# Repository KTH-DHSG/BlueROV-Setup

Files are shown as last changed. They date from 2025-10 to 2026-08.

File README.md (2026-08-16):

# BlueROV-Setup

- [Using the BlueROV](setup_instructions/Usage.md): How to get started on a readily-prepared system
- [PX4 setup](setup_instructions/PX4_setup.md): How to set up software and communications
- [Jetson OS and CUDA setup](setup_instructions/Jetson_setup.md): Flashing Linux with support packages, installing CUDA, and remote desktop
- [Jetson software setup](setup_instructions/scripts/BlueROV_Jetson_setup.sh): Install script for a newly flashed Jetson
- [Internet on Jetson](setup_instructions/Jetson_internet.md): Getting internet access to Jetson via tether
- [Hardware setup](setup_instructions/hardware_setup.md): Internal hardware setup
- [Docking station setup](setup_instructions/docking_station.md): Setting up, modifying and using the docking station
- [SITL Simulation setup](setup_instructions/sim_setup.md): PX4 gz STIL simulation setup
- [Wiring diagram](setup_instructions/brov-wiring-diagram-inkscape.svg): for more details on our specific hardware adaptations

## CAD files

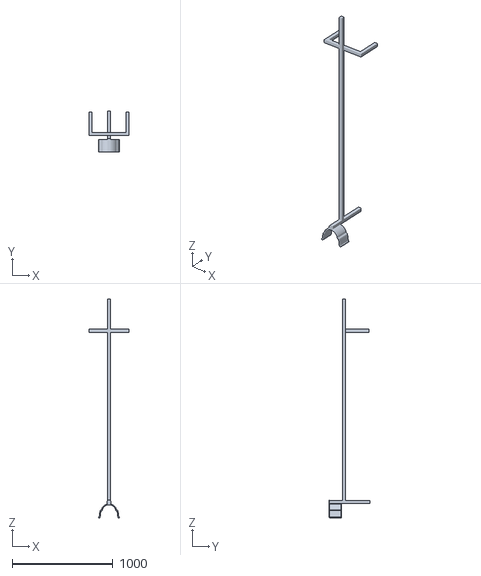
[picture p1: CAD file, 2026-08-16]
STLs/docking_station/docking station simplified.obj
400.0 x 402.0 x 2172.2

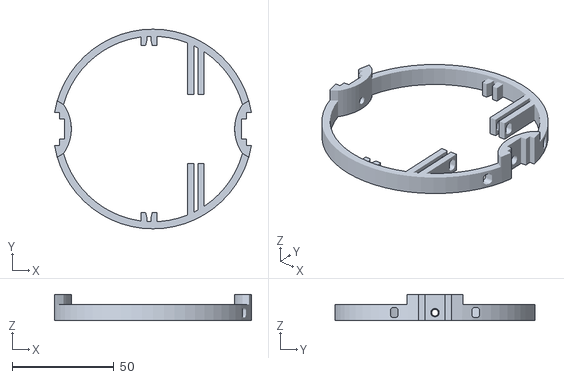
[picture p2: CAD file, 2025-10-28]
STLs/JetsonHold_ToUseAtFrontside.stl
96.7 x 98.0 x 13.0

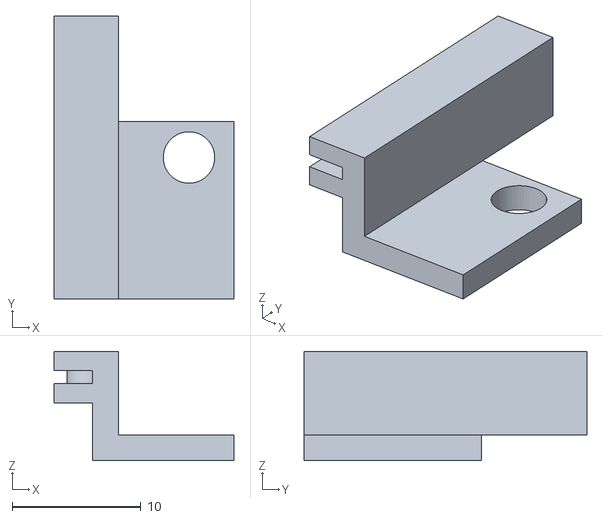
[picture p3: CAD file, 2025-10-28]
STLs/NvmeAdapter.stl
14.0 x 22.0 x 8.50

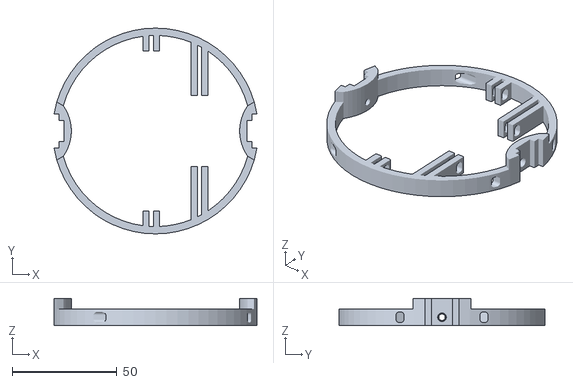
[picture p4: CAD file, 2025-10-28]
STLs/JetsonHold_ToUseAtBackside.stl
96.7 x 98.0 x 13.0

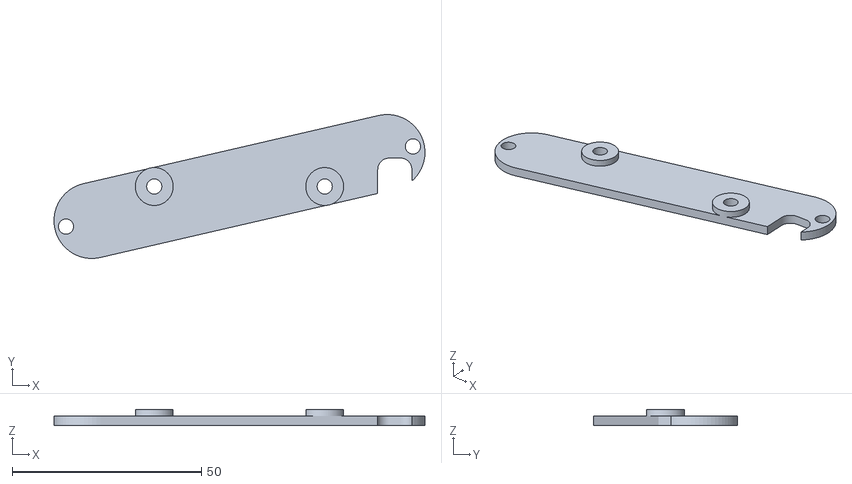
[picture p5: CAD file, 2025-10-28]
STLs/CameraHold.stl
97.9 x 38.0 x 4.30

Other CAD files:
STLs/docking_station/DockingStationv2.step
STLs/docking_station/DockingStationv2.FCStd
STLs/docking_station/DockingStationv2.stl

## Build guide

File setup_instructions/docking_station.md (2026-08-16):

# Docking station

## Introduction

The docking station was made to allow for "parking" the BlueROVs (BROV) in the water tank. The assumption is that the robot is slightly bouyant as this way it will flow up and press against the docking shell making it locked in space. The docking shell was made in such a way to allow both the BROV with the extra tube on top as well as the one without the extra tube to be able to dock in it. Admittedly, it is better for docking the BROVs with extra tube on top as it is fits better into the shell.

<p align="center">
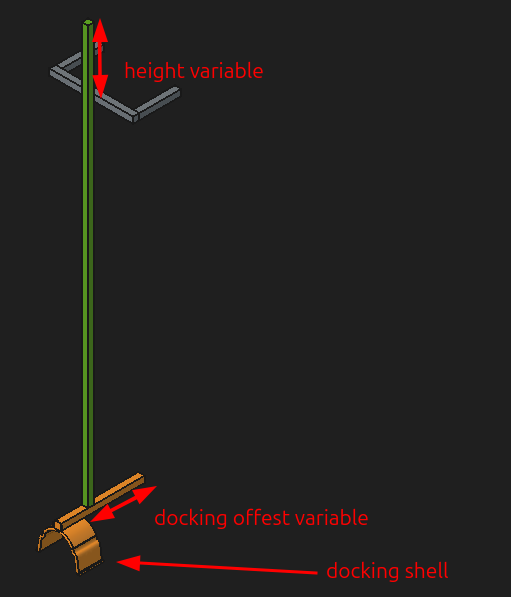
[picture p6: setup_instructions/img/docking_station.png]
  
</p>

## Files

There are four different CAD files in different formats that can be used for your project [`.obj`](../STLs/docking_station/DockingStationv2.obj), [`.step`](../STLs/docking_station/DockingStationv2.step), [`.stl`](../STLs/docking_station/DockingStationv2.stl) and [`.FCStd`](../STLs/docking_station/DockingStationv2.FCStd).

## Customization

If you need to make any changes to this setup feel free to do so. The docking station was made in [FreeCAD](https://www.freecad.org/downloads.php). It's free, open source and supported on Windows, Mac and Linux. [`.FCStd`](STLs/docking station/DockingStationv2.FCStd) is its native file format and allows for the greatest freedom in customization as well as [exporting into various other file formats](https://www.xsim.info/articles/FreeCAD/en-US/HowTo/Supported-file-formats.html). Within that file you can also export and customize the inidvidual components of the docking station.

If you simply need to change the height and docking offest values you can do so by changing the VarSet values of the name `docking station params`.

<p align="center">
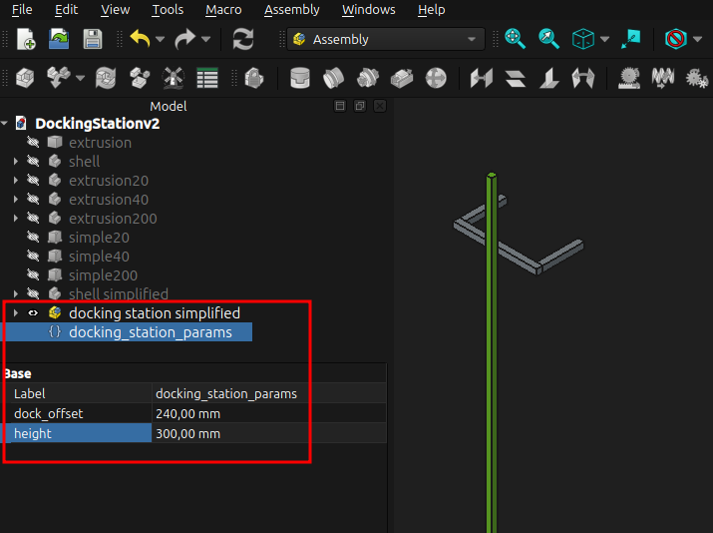
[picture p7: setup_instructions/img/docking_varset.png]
  
</p>

Feel free to explore the CAD file. There are more variables for detailed adjustments of the docking shell, its dimensions as well as the aluminum extrusion arrangement.

## Debugging

- There is an issue with exporting `.obj` files in FreeCAD 1.1.0. Exporting the part into an STL file and then opening that file and exproting it into OBJ file does the trick though.

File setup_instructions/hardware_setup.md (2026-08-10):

# Hardware Setup

This article is concerned with the internal setup of the robots. It is directed at everyone who wants to do own modifications on the hardware. For usage instructions, see [here](Usage.md).

The basic hardware setup follows the instructions by [Blue Robotics](https://bluerobotics.com/learn/bluerov2-assembly) (**Note:** Make sure to select the "Heavy configuration" when looking at the instructions.). In addition, some modifications have been made:

- Replaced flight controller from BlueRobotics/Raspberry Pi-based with PX4 Autopilot (Holybro PX6X)
- Added top tube
- Added Jetson Orin NX
- Added Intel Realsense
- Added network switch
- Software setup, not the scope of this page

The hardware instructions can still be useful for (e.g.)

- assembly of the battery tub and central tube
- how to make the robot waterproof (and test that it actually is)
- ESC setup
- how individual parts s.a. Fathom-X tether work
- ...

It is recommended to take a look at them!

## Overview

The BlueROV has three tubes:
1. Lowest:
	- Standard kit, unchanged
	- Contains battery
2. Mid:
	- Standard kit
	- Main "brain" of the robot: Contains all essential parts such as
		- Flight controller (PX6X)
		- ESCs
		- Tether interface
		- barometer, gyroscope (latter one built into PX6X)
		- ...
	- Tubes 1 and 2 are essential to control the robot in any way, even manual
	- Modification:
		- Added ethernet switch
		- Added a combined power/ethernet connection to the top tube
3. Upper:
	- Our own mod
	- Adding more autonomous capabilities through adding
		- Jetson Orin NX 16GB with [carrier board](https://connecttech.com/product/boson-for-framos-carrier-board-for-nvidia-jetson-orin-nx/)
		- Intel RealSense D435i

For a more detailed view, take a look at the wiring diagram.

## Motor setup

The motor assignments in PX4 follow the numbering of BlueRobotics:

<p align="center">
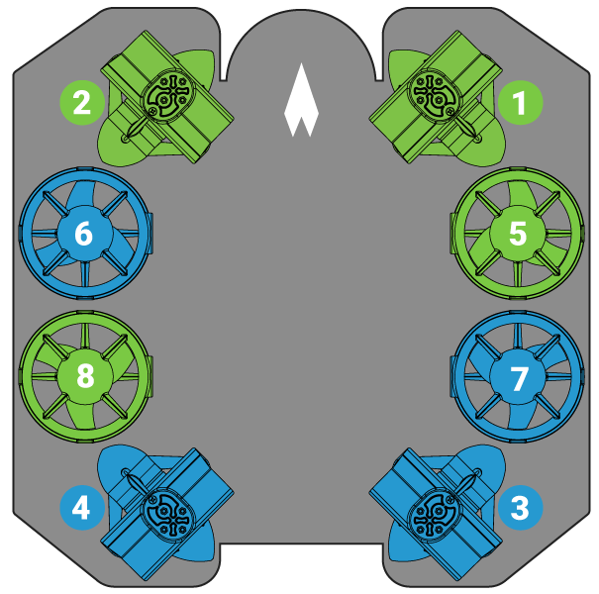
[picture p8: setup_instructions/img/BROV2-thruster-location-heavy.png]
  
</p>

<details>

<summary>💡 Help! I send the correct signal, but the wrong motors turn!</summary>

Let's say you want motor 1 and 2 to move and send an appropriate signal. Instead, motor 5 and 6 move.

In less evolved systems, you would need to make sure that the correct PWM output is connected to the correct motor. PX4, however, gives an easy way around this common problem:

Under `Q > Vehicle Setup > Actuators`, you can got to the 'PWN MAIN'/'PWM AUX' tab. For each PWM output, you can select a routing of the output in the dropdown, i.e. that 'MAIN 1:' is 'diabled', acts as 'Motor 1', ...

You can try out the current routing in the 'Actuator Testing' tab and move each motor individually. (Take care of your fingers and other vulnerable things. Also don't run the motors for too long, they are designed to operate in water and will overheat outside.)

<p align="center">
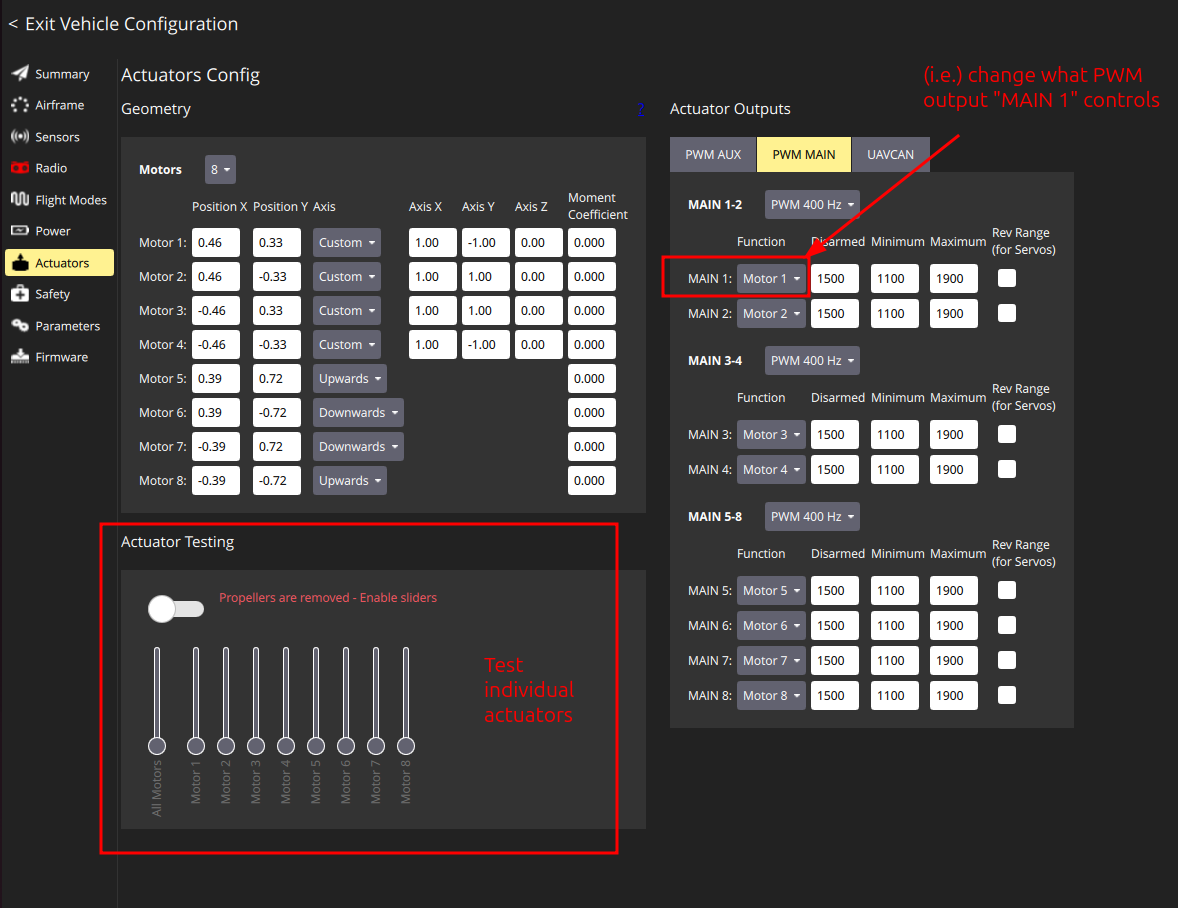
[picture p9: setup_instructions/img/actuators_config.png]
  
</p>

</details>

## Vacuum testing

If new tubes / cables between tubes / ... are installed, a prelimiary vaccum test should be preformed. In general, the instructions from BlueRobotics [here](https://bluerobotics.com/learn/bluerov2-assembly/#preliminary-vacuum-test) can be followed. Make sure to

- Start with the equipment test. If the vacuum pump + connections themselves are not tight, try with zip ties.
- Test all tubes at the same time, otherwise it will not work. Combine as many T-formed hose connectors as you need to connect to all tubes.
- Disassemble the equipment after use: Over time, the hoses will otherwise take the shape of the connectors, so the pressure at the connection pieces decreases and they will start to leak air.

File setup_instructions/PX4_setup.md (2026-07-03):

# PX4 Setup

---

## Table of Contents

- [What's PX4?](<PX4_setup#What's PX4?>)
- [Interfaces](PX4_setup#Interfaces:)
- [Flashing and Setting up PX4](<PX4_setup#Flashing and Setting up PX4>)
- [Communication Setup](<PX4_setup#Communication Setup>)
  - [User-side setup](<PX4_setup#User-side setup>)
  - [BlueROV-side setup](<PX4_setup#BlueROV-side setup>)
    - [Jetson](PX4_setup#Jetson)
    - [PX4](PX4_setup#PX4)
    - [PX4 Setup](<PX4_setup#PX4 Setup>)
- [Common Issues](<PX4_setup#Common Issues>)

---

## What's PX4?

- open software/hardware project serving as "brain" for all sorts of drones
- Advantages:
  - Good software intergration: Easy integration of sensors etc., safety features, controller integration, ...
  - Open Source: Multiple manufacturers produce for PX4, if one product is discontinued, there is a plug-and-play replacement from another manufacturer.
  - Good software integration with e.g. QGroundControl
- Do not confuse:
  - PX4 Autopilot: The open-source system/project itself
  - PX6X: The specific hardware on which we are running PX4 Autopilot

</details>

## Interfaces:

- Physical Interfaces
  - Tether:
    - connect Fathom-X tether interface via USB to your computer
    - Establishes an ethernet connection to the whole BlueROV (i.e. the PX6X, but also e.g. the Jetson)
    - setup instructions: see below (todo: insert link)
  - USB-C:
    - connect directly from your computer to PX6X (requires removal of tube)
    - Fallback if PX6X is not available over Ethernet
    - For now needed to update the firmware of the PX6X
- Software interfaces:
  - QGroundControl
    - Allows to set most settings in an easy-to-use graphical interface
    - Console interface under "Analyze Tools > MavLink Console" for advanced use cases
  - ROS2 interface: MavLink to ROS2 bridge (todo: insert link)

---

## Flashing and Setting up PX4

Theoretically, the flashing should be easily doable through QGroundControl ([PX4 Doc > Config > Firmware](https://docs.px4.io/main/en/config/firmware.html)). For current firmware version v1.16.0 this however leads to an incomplete install (BlueROV airframe not selectable), so this procedure works instead:

Follow the [spacelab setup](https://atmos.discower.io/pages/PX4/) for the first three steps ("PX4 Autopilot" section).

The firmware installation works similar, but we choose a _different target_ and _different default namespace_:

1. Connect the Pixhawk to your computer via serial. Make sure QGroundControl is closed.
2. Navigate to the cloned PX4-Autopilot directory and ensure that the build environment is clean.

```bash
make clean
```

3. Export the name of the robot to setup the DDS.

```bash
export PX4_UXRCE_DDS_NS=<robot_name>
```

4. Upload the firmware using:

```bash
make px4_fmu-v6x_uuv upload
```

> [!Note]
> The target we use below is currently only available in the development release (v1.16.0.rc1), not in the latest stable release.

---

## Communication Setup

Communication mainly follows standard networking approaches -> Knowledge of setting up IP networks is advantageous

- Fathom-X is simply a transparent ethernet bridge (without own IP adress or so), whole network is a standard ethernet network
- PX6X needs to be configured for communication over Ethernet. General instructions are under [PX4 docs > Advanced Config > Ethernet Setup](https://docs.px4.io/main/en/advanced_config/ethernet_setup), our setup follows:

Goal: Have all three BlueROVs connected to the same computer

Current setup: Follow original setup closely

USB-Switch connecting to all Fathom-X interfaces. Each USB-cable should be detected as individual USB-ethernet interface in system network settings.

### User-side setup

Probably the easiest is to connect and set up one BlueROV at a time. Each Fathom-X Interface box (FXTI) connection gets its own network setting with own IP adress and subnet.

| BlueROV | Laptop IP | Subnet Mask (Netmask) | Gateway | Status |
| --- | --- | --- | --- | --- |
| Splash | 192.168.0.1 | 255.255.255.0 | 0.0.0.0 | Done |
| Bubble | 192.168.1.2 | 255.255.255.0 | 0.0.0.0 | Done |
| Glub | 192.168.2.3 | 255.255.255.0 | 0.0.0.0 | To be done |

1. Go to Settings > Network > Add
2. Under Identity > Name, choose
   - a profile name (we suggest the name of the BROV)

3. Under IPv4, choose
   - IPv4 Method: Manual
   - Fill the corresponding fields from the table above

4. Apply settings

> [!NOTE]  
> The first time you connect to QGC with the BlueROV2 and the Fathom, it can take a long time for the PX4 to be detected.

### BlueROV-side setup

#### PX4

The network setup on robot side can be changed through QGroundControl. The current configuration is

| BlueROV | UXRCE_DDS_KEY | Fathom (Laptop) IP | PX4 IP | Subnet Mask | Status |
|---|---|---|---|---|---|
| Splash | 1 | 192.168.0.1 | 192.168.0.10 | 255.255.255.0 | Done |
| Bubble | 2 | 192.168.1.2 | 192.168.1.11 | 255.255.255.0 | Done |
| Glub | 3 | 192.168.2.3 | 192.168.2.12 | 255.255.255.0 | To be done |

>[!Important]
> Each BROV should have a different UXRCE_DDS_KEY. This can be changed in the parameters tab in QGroundControl.

To ensure that we can run multiple BROVs at the same time, we must ensure that they run on separate subnets. They should already be set correctly and **we recommend to not touch this**, but in case you need to you can change them by doing the following: go to "Analyze Tools > MavLink Console". Then type params (or any other keyword) so that you can see the console shows "nsh>" instead of just ">". Then input:

```
# Splash
echo DEVICE=eth0 > /fs/microsd/net.cfg
echo BOOTPROTO=fallback >> /fs/microsd/net.cfg
echo IPADDR=192.168.0.10 >> /fs/microsd/net.cfg
echo NETMASK=255.255.255.0 >> /fs/microsd/net.cfg
echo ROUTER=192.168.0.1 >> /fs/microsd/net.cfg
echo DNS=192.168.0.1 >> /fs/microsd/net.cfg
reboot
```

```
# Bubble
echo DEVICE=eth0 > /fs/microsd/net.cfg
echo BOOTPROTO=fallback >> /fs/microsd/net.cfg
echo IPADDR=192.168.1.11 >> /fs/microsd/net.cfg
echo NETMASK=255.255.255.0 >> /fs/microsd/net.cfg
echo ROUTER=192.168.1.2 >> /fs/microsd/net.cfg
echo DNS=192.168.1.2 >> /fs/microsd/net.cfg
reboot
```

```
# Glub
echo DEVICE=eth0 > /fs/microsd/net.cfg
echo BOOTPROTO=fallback >> /fs/microsd/net.cfg
echo IPADDR=192.168.2.12 >> /fs/microsd/net.cfg
echo NETMASK=255.255.255.0 >> /fs/microsd/net.cfg
echo ROUTER=192.168.2.3 >> /fs/microsd/net.cfg
echo DNS=192.168.2.3 >> /fs/microsd/net.cfg
reboot
```

Rebooting through the MavLink Console sometimes does not work. You can also go to Vehicle Configuration > Parameters tab and then click Tools > Reboot Vehicle.

Now you should be able to run the Micro-XRCE-DDS-Agent and use ROS2 topics as described in the simulator section: [sim_setup.md](sim_setup.md). 

>[!Note] Note that if you have changed the Fathom (laptop) address you need to change the UXRCE_DDS_AG_IP parameter in the Parameters tab of QGC to the signed int32 equivalent of your Fathom IP address.

#### Jetson

Under Settings > Network > Realtek Ethernet set a static IP with the addresses stated above. The process is the same one as the user-side setup without the extra steps.

> [!IMPORTANT]
> This setup does _not_ allow the Jetson to access the internet. To achieve this, two methods are possible (plus the alternative setup described below).
>
> 1. Enable IP forwarding and set up NAT (Network Address Translation) on your desktop computer
> 2. Take of the shell on the front (camera side), connect an ethernet cable to the second ethernet port of the Jetson
>    Personally, I think that the alternative setup has a lot of advantages and simplifies working with the robots a lot.
---

## Common Issues
PX4 Issues:

1. Micro XRCE DDS doesn't connect to the companion laptop.
   When the Micro XRCE DDS agent doesn't detect the DDS client running on PX4, it most likely means that the IP set for the companion laptop is not the same set in the DDS config. To check the IP targeted by the client on PX4, do the following: Open **QGround**/**Analyze Tools**/**MAVlink Console** and type in the terminal

   ```bash
    xrce_dds_client status
   ```

   This should output the current targeted IP of the DDS client running on PX4. Make sure the companion computer that is supposed to receive the ROS2 messages has the same IP configured in the network settings.

   The IP used by the DDS client on PX4 can be changed if need be. To do so go into **QGround**/**Parameters** and search for **XRCE_DDS_IP_AG** and change that parameter to the IP you want the client to target.

   > [!Caution]
   > The parameter used in QGround is in `int32` format so the IP has to be converted to a binary representation first and then saved in `int32`. This can be done using C/C++ type `int32_t`.

2. Gazebo simulation doesn't have the BROV2 models.
   The PX4 repository used for the PX4 flashing is the official one, hence it doesn't have the required files for Gazebo simulation. To get the PX4 fork that has the Gazebo files, follow the simulation instructions here [https://github.com/KTH-DHSG/BlueROV-Setup/blob/main/setup_instructions/sim_setup.md](https://github.com/KTH-DHSG/BlueROV-Setup/blob/main/setup_instructions/sim_setup.md)

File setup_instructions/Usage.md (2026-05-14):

# Quick tutorial

This is a short tutorial on how to use the BlueROVs. We recommend first doing the SITL gz simulator setup in [SITL Simulation setup](sim_setup.md).

## Table of Contents
- [Open and close the tubes](#open-and-close-the-tubes): Open and close the BlueROV, e.g. for loading batteries
- [Operate in manual mode](#operate-in-manual-mode): Establish connection to robot, arm the robot, manual steering
- [Connect to Jetson](#connect-to-jetson): Connect your PC/laptop to the Jetson
- [Start PX4/ROS communication](#start-px4ros-communication): Establish the bridge between PX4 messages and ROS messages. Allows to record data/control over ROS/...
- [Setup lights switch](#lights-switch): how to setup the lights to a Joystick switch.

## Operate in manual mode

1. Setup: If not already happened, 
- Install QGroundControl from the official resources
- Make sure to follow the user-side setup in [PX4_setup.md](PX4_setup.md).

> [!NOTE]
> If you are operating **Bubble** (the BlueROV2 without the extra tube with the stereo d435i cam and the Jetson) ignore all the instructions from the [Connect to Jetson](#connect-to-Jetson) all the way to the end. 

2. Connect the battery to the XT90 connector (check the [Open and close the tubes](#open-and-close-the-tubes) section to know how open the tube where it resides). Make sure to hear the two difference notes with a space of about 3s of silence in between, if you only hear a continuous song the BlueROV2 has not started the ESCs correctly and you need to unplug and plug the battery again. Another way to see if it has started correctly is that the PX4 should have two continuous lights, a green and an orange one.
<p align="center">
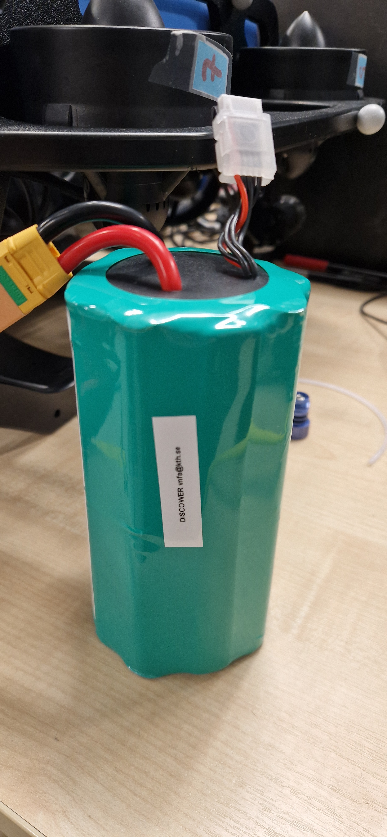
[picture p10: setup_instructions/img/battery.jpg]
  
</p>

3. Connect the Fathom-X Interface with a USB port on your computer on the one side and with the BlueROV tether on the other.

<p align="center">
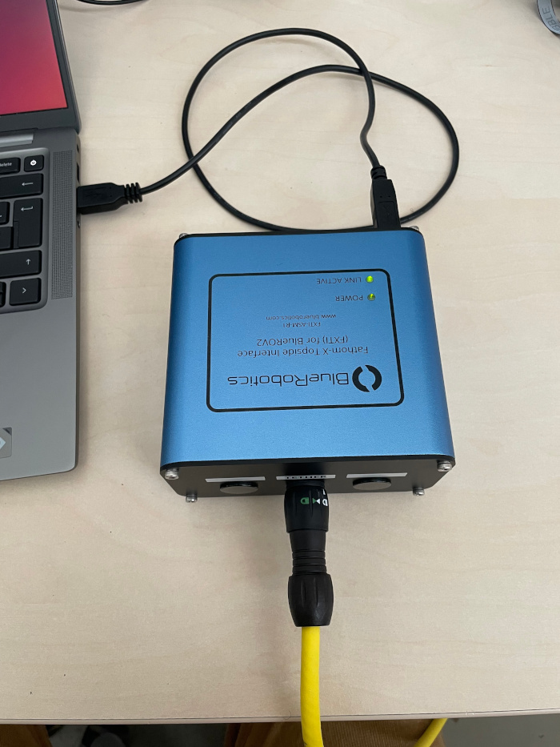
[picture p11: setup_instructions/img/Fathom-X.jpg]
  
</p>

4. Open QGroundControl. After a short while, the robot should be connected and it should look like this:

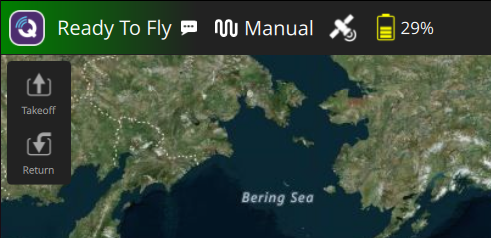
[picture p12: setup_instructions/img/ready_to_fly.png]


> [!NOTE]
> It might also look like this:
>
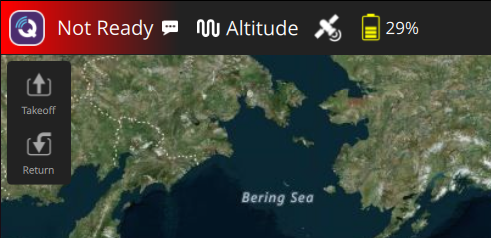
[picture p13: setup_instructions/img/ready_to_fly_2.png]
> 
> 
> You can most probably ignore this warning. If not, QGroundControl will give you a helpful error during arming.
> 
> <details> <summary>Reason for warning:</summary> This can happen as no "classical" radio remote control is configured - we use the BlueROV only via QGroundControl and Joystick. You can ignore the red "Not Ready" therefore, the vehicle is connected anyways. To verify that this is the reason for the warning, go to "Q">"Vehicle Configuration". Everything should be green besides of "Radio". </details>

If the robot is not connected after some time, remove and re-plug the USB connection. If the issue persists, check your network setup.

5. Plug in the joystick, arm the vehicle and have fun! If you are connected, but something is not working, go to "Q">"Vehicle Configuration" and resolve the issues (most likely you need to tick the Enable joystick box in the Joystick tab).

To arm the vehicle, make sure that "Manual" mode is selected from the dropdown in the top bar. Then, click the following:

<p align="center">
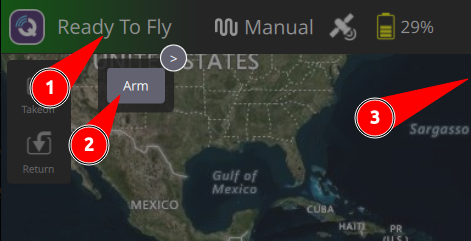
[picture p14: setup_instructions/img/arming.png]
   
</p>

We also strongly recommend to setup an arm (button 6 in xbox) and a disarm (button 4 in xbox) button before any operations so you can safely and quickly disarm it if needed. This can be setup in Vehicle Configuration > Joystick > Button Assignment.

Connecting the Xbox controller through Bluetooth is also always recommended to reduce the number of cables in the tank. To do so you need to first turn the controller (maintain press on the Xbox symbol - turning it off is done by a longer maintain press) and put it in binding mode (press the smaller button on the top of the controller). You should then be able to see and pair it using common Ubuntu Bluetooth window. If you are experiencing issues we recommend installing the [xpad-neo](https://github.com/atar-axis/xpadneo) driver and updating the firmware in the controller (through the Windows Xbox app). To test it works you can use the [gamepad testet](https://hardwaretester.com/gamepad).

> [!NOTE]
> Other people might bind your controller while you are away and you will need to re-pair it again afterwards, if you are seeing your controlling connecting and disconnecting from Bluetooth really fast, you need to re-pair.

<p align="center">
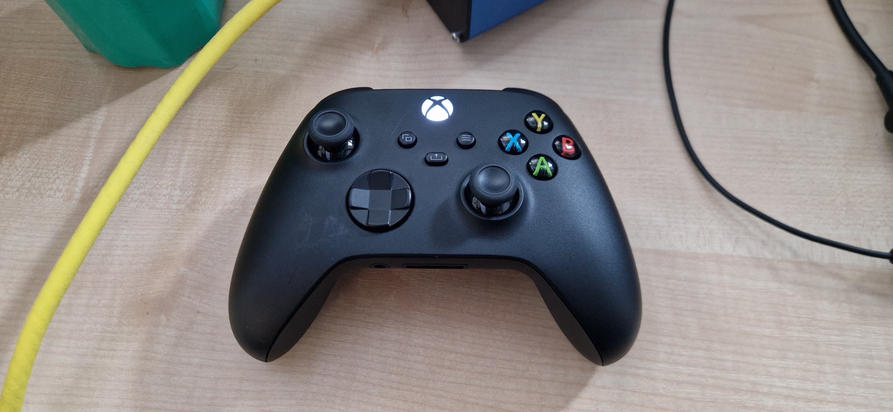
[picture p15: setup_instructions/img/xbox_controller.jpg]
   
</p>

For control over ROS, you need to [start ROS communication](#start-px4ros-communication) and change the mode to "offboard". **NOTE that for Bubble we use a different connection setup, described in the BlueROV-side setup section in [PX4_setup.md](PX4_setup.md).**

## Connect to Jetson

1. See steps 1 and 2 above. 

2. Verify that you have a connection to the robot by opening QGroundControl or 
```
ping 192.168.0.<your robots IP>
```

3. Connect to the Jetson over SSH via
```
ssh discower@<jetson_IP>
```
for user and PW 'discower'. If it does not work, change the username from discower to glub or splash (depending on which robot you use).

4. Optional: Start all ROS services, e.g. start the Intel RealSense node.
```
ros2 run realsense2_camera realsense2_camera_node
```

> [!NOTE]
> The Jetson has by default no access to the internet. Refer to [PX4_setup.md](PX4_setup.md) for more information regarding package installation etc.

## Start PX4/ROS communication

PX4 and ROS2 can communicate using the [MicroXRCE-DDS client](https://docs.px4.io/main/en/ros2/user_guide#installation-setup). The client should already be installed on the Jetson. Once it is started, you can see all PX4 topics in ROS and command the robot from ROS. Start the connection like this:

1. SSH to the Jetson and call
```
MicroXRCEAgent udp4 -p 8888
```
2. In QGroundControl, go to "Q">"Analyze Tools">"MAVLink Console" and call
```
uxrce_dds_client start -t udp -p 8888 -h <JETSON_IP>
```

You can test your connection using `ros2 topic list`.

## Open and close the tubes

**Opening the tubes**

1. Remove the locking chord

<p align="center">
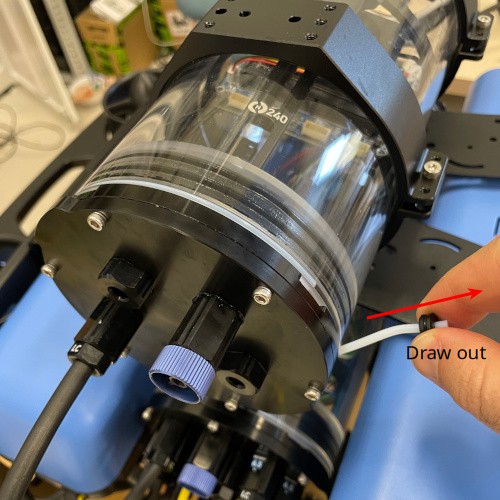
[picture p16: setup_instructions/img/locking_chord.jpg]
  
</p>

2. Remove the pressure relief valve

<p align="center">
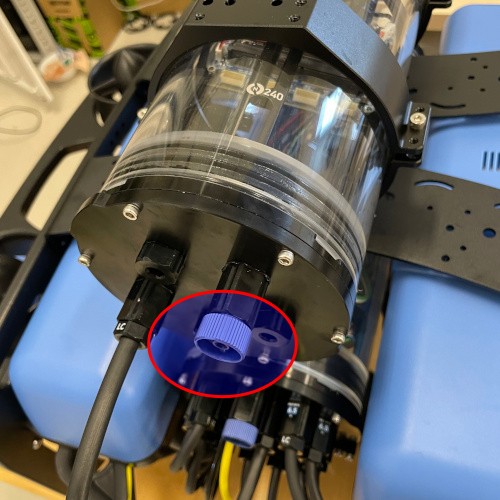
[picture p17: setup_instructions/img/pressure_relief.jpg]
  
</p>

3. Detach the end cap with the black enclosure prying tool

<p align="center">
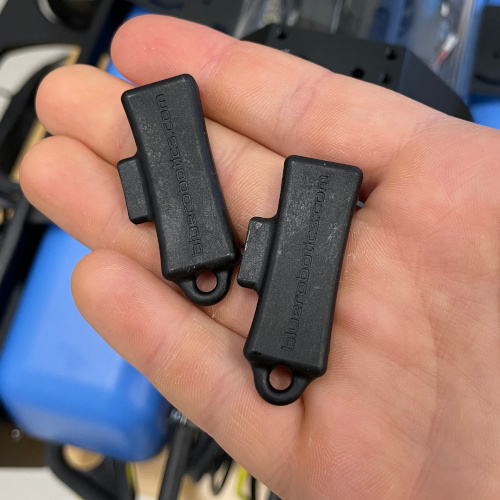
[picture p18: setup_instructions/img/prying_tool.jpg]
  
</p>

<p align="center">
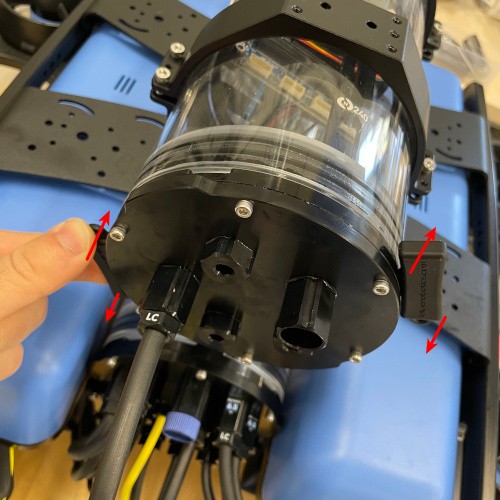
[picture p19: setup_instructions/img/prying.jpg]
  
</p>

**Closing the tubes**

Basically everything in reverse:

1. Make sure the pressure relief valve is detached
2. Press in the end cap. Make sure that no cable is damaged
3. Attach the pressure relief valve
4. Attach the locking chord. They come in different lengths depending on tube size.

## Lights switch
1. To setup the light switch you first need to modify your QGC. Go to Documents/QGroundControl/MavlinkActions folder and add a file called actuators.json with the following inside:
```bash
{
  "version": 1,
  "fileType": "MavlinkActions",
  "actions": [
    {
      "label": "Lights ON",
      "description": "Turn lights on",
      "mavCmd": 187,
      "param1": 1
    },
    {
      "label": "Lights OFF",
      "description": "Turn lights off",
      "mavCmd": 187,
      "param1": -1
    }
  ]
}
```

2. Next, enter QGC, go to the Application Settings > Fly View and in MavLink Actions select your actuators.json for both Fly View Actions and Joystick Actions.

3. Then, go to Vehicle Configuration settings > Actuators, and in the PWM AUX tab on the right select the first AUX 1 to be Peripheral via Actuator Set 1.

4. Lastly, go to Joystick > Button assignment and setup one button to be Lights ON and one to be Lights OFF. Now you can arm the vehicle and test the lights!

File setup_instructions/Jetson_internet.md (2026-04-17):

# BROV Jetson Internet Connection Setup

## Description

The goal of this tutorial is to allow the Jetson computer access the internet via the BROVs ethernet thether connection.

## Prerequisites

You need to first setup the ethernet connection between BROV and your laptop. If you are able to ssh to Jetson then you're good in that regard.

## Procedure

### Laptop-side setup:
First, we need to find the network devices that interface the Internet \<Internet-facing\> and the BROV2 \<LAN-facing\>.

To find \<Internet-facing\> we run:
```bash
ip route | grep default
```
Which can produce ouput similar to this:
```bash
default via 10.0.0.1 dev enxc0470e89b222 proto dhcp metric 103 
default via 10.0.0.1 dev wlp113s0f0 proto dhcp metric 600 
```
The \<Internet-facing\> can be then either <code>enxc0470e89b222</code> which is the ethernet adapter connected to the lab, and <code>wlp113s0f0</code> which is the WiFi adapter.

To find \<LAN-facing\> we run (in a similar fashion):
```bash
ip route | grep 192.168
```
Which can produce the output:
```bash
192.168.0.0/24 dev enx00e03336699a proto kernel scope link src 192.168.0.3 metric 102
```
Now, the last IP address in the line above is the IP we assigned to the laptop using the GUI when first setting up the network over the tether.

```bash
# configure the iptables
sudo iptables -t nat -A POSTROUTING -o <Internet-facing>  -j MASQUERADE
sudo iptables -A FORWARD -i <Internet-facing> -o <LAN-facing> -m state --state RELATED,ESTABLISHED -j ACCEPT
sudo iptables -A FORWARD -i <LAN-facing> -o <Internet-facing>  -j ACCEPT
```
Then save the config to make it pesistent:
```bash
# donwload persistent iptables and save the current settings
sudo apt install iptables-persistent
sudo netfilter-persistent save

# make the forwarding permament
echo "net.ipv4.ip_forward=1" | sudo tee -a /etc/sysctl.conf
sudo sysctl -p
```

### Jetson-side setup:
All of the required changes to the settings should have been already installed automatically by this stage of the setup process.

**Check**:
```bash
sudo cat /etc/netplan/01-netcfg.yaml
```
If nothing is displayed, it means that the automatic setup was unsuccessful and the following needs to be done on the Jetson.

**Option 1**: Use the script <code>jetson_internet_setup.sh</code> located in the <code>scripts/</code> directory.

**Option 2**: Follow the tutorial below:

Find Jetson LAN-facing device:
```bash
ip route | grep default
```
Which produces very similar output to the previous cases. Chose the device that has the LAN connection. We will call it \<Jetson-LAN-facing\>

```bash
# download netplan
sudo apt install netplan.io

# create a new netplan rule
sudo tee /etc/netplan/01-netcfg.yaml << 'EOF'
network:
  version: 2
  ethernets:
    enP8p1s0:
      dhcp4: false
      addresses:
        - 192.168.0.22/24
      routes:
        - to: default
          via: 192.168.0.3
      nameservers:
        addresses: [8.8.8.8, 8.8.4.4]
EOF

# fix the permissions and apply
sudo chmod 600 /etc/netplan/01-netcfg.yaml
sudo netplan apply
```
**IMPORTANT!** Change the Jetson's network device name from <code>enP8p1s0</code> to \<Jetson-LAN-facing\>.
This netplan setup assumes the laptop has configured its IP to be <code>192.168.0.3</code>, so adjust this line if the IP is different. Similarily, the IP <code>192.168.0.22/24</code> is the IP we want to assign to the BROV2, change this line if you want a different one.

Now check if the Jetson has access to the Internet:
```bash
# ping google to see if it resolves
ping -c 3 google.com
# ping the laptop to see if it resolves
ping -c 3 192.168.0.22

```

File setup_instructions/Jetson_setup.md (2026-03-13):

# Jetson OS and CUDA Setup

This tutorial encopases all that is needed to install Linux operating system with ConnectTech support packages.

## Table of Contents

- [Jetson OS and CUDA Setup](#jetson-os-and-cuda-setup)
  - [Table of Contents](#table-of-contents)
  - [Before Installation](#before-installation)
  - [Flashing Jetson with the Operating System](#flashing-jetson-with-the-operating-system)
  - [Configuring Internet Access](#configuring-internet-access)
  - [Installing Nvidia SDK](#installing-nvidia-sdk)
  - [Software Setup After Installation](#software-setup-after-installation)
    - [Setting up remote desktop using NoVNC](#setting-up-remote-desktop-using-novnc)
    - [Setting up Nvidia TensorRT for YOLO acceleration](#setting-up-nvidia-tensorrt-for-yolo-acceleration)
  - [Reference Links](#reference-links)

## Before Installation

Before we can begin the installation process, we need to install [Nvidia SDK Manager](https://developer.nvidia.com/sdk-manager). This step requires an active Nvidia account and unfortunately cannot be skipped.

1. Enable the recovery mode on the Jetson. To enable the recovery mode follow the steps described in the [manual](https://connecttech.com/ftp/pdf/CTIM-00095_Boson_Boson22_Manual.pdf). In short, connect the Jetson to its power supply, press and hold the recovery button (SW3) and press-release the reset button (SW2). When in the recovery mode, the radiator fan should spin at maximum speed.

2. Connect the Jetson using its USB C port to your computer.

## Flashing Jetson with the Operating System

1. Open Nvidia SDK Manager.

2. Select Jetpack 6.2 rev. 2 (it can be hidden under all versions button).
<p align="center">
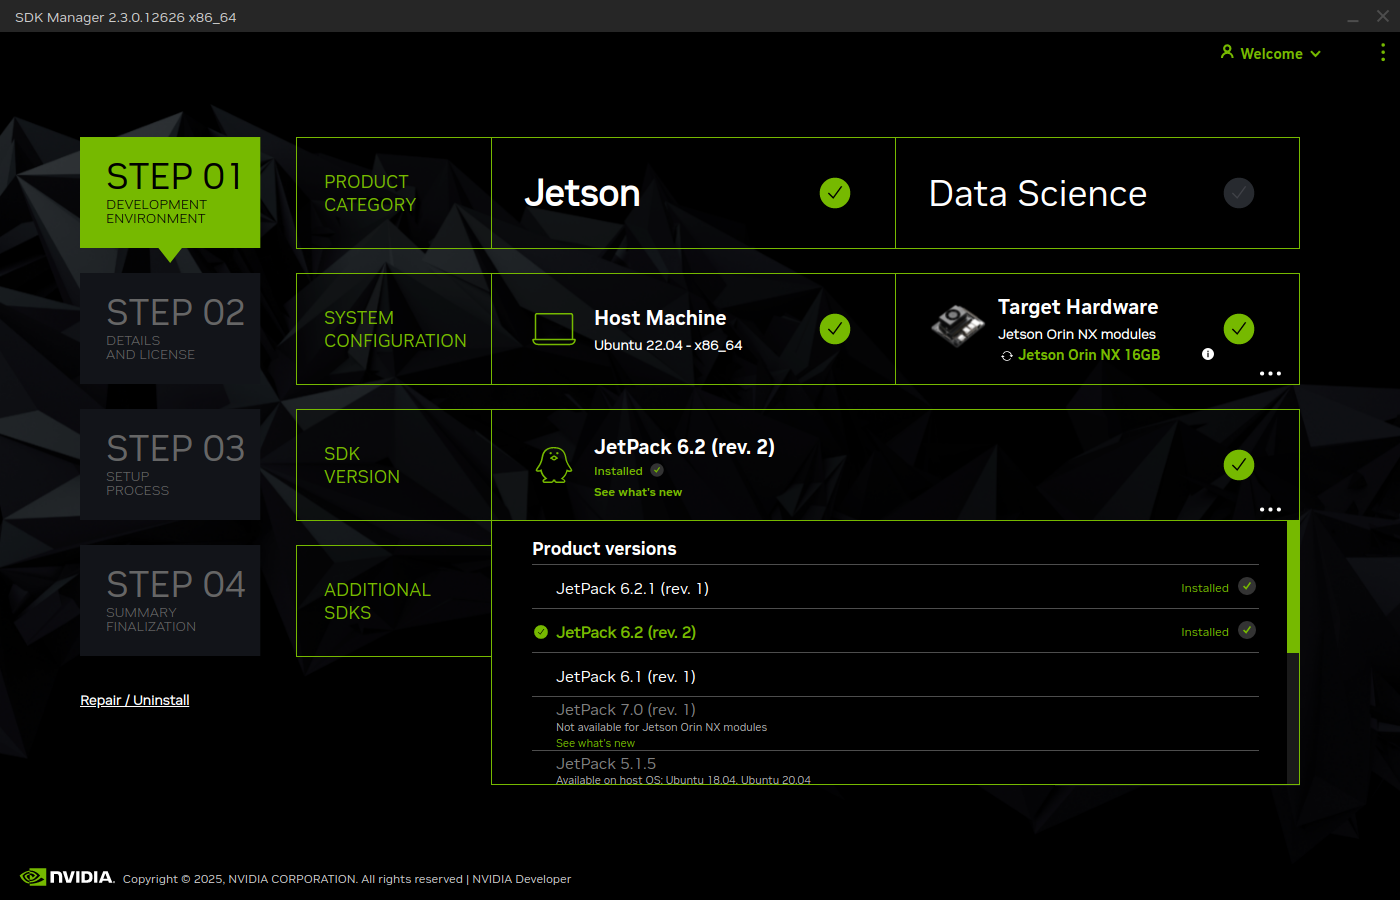
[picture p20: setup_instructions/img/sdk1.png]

</p>
3. Select the following modules to be installed:
<p align="center">
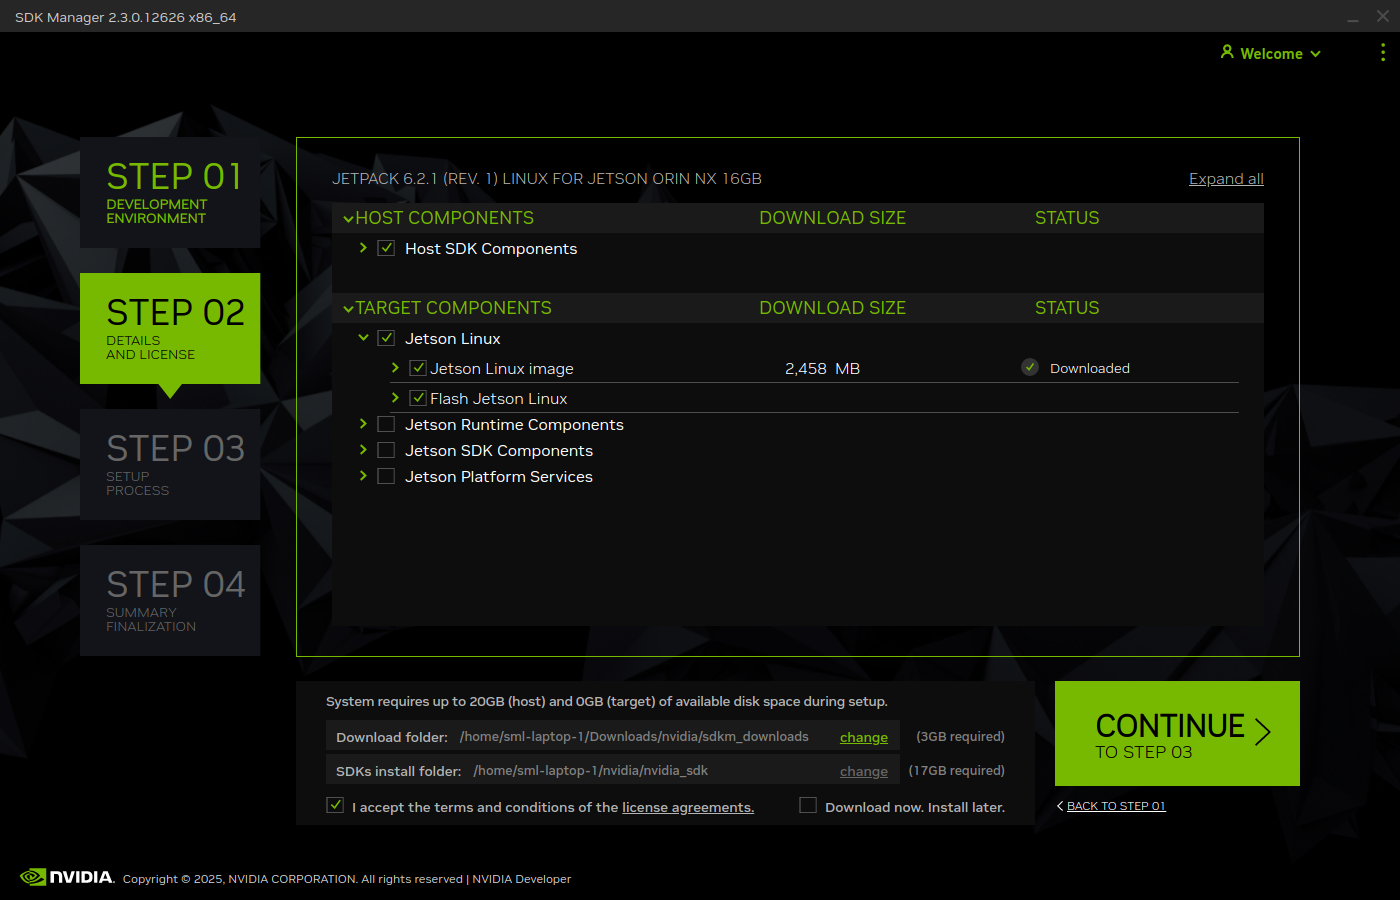
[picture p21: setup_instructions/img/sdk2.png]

</p>
4. After downloading the modules, on the prompt to flash the board, press skip.
5. Download a suitable [CTI support package for Jetpack 6.2](https://connecttech.com/resource-center/l4t-board-support-packages/) (DO NOT download RealTime OS), or use this [direct link to the package](https://connecttech.com/ftp/Drivers/CTI-L4T-ORIN-NX-NANO-36.4.3-V009.tgz). Make sure that the extracted folder containing the files is named <strong>CTI-L4T</strong>.
6. Unzip the support package archive and make sure the top-most folder is called <strong>CTI-L4T</strong> and place it here: <code>/home/$USER/nvidia/nvidia_sdk/JetPack_6.2_Linux_JETSON_ORIN_NX_TARGETS/Linux_for_Tegra</code> where <strong>$USER</strong> is your account username.

7. From terminal, go into <strong>CTI-L4T</strong> directory and execute \
   <code>sudo chmod +x install.sh</code> \
   <code>sudo ./install.sh</code> \
   <code>cd ..</code> \
   <code>sudo ./cti-flash.sh</code>
8. When prompted, select the appropriate settings for the current board (Boson for Orin, Orin NX, Base, Default).
9. <strong>TIP!</strong> After flashing is complete disconnect the USB C cable from the computer flashing the Jetson (after the flashing script exits). Sometimes it may prevent the Jetson from booting up and flashing will have to be done again.

## Configuring Internet Access

To proceed with the configuration, we have to enable Internet access. One way of doing this is to connect the Jetson with an ethernet cable to the local network and using one of the monitors in the lab to proceed with the basic Linux user setup. After that is complete, open the terminal and get the assigned IP address using the command:

<code>hostname -I</code>

For configuring the Internet access with the tether attached, see [Getting internet access to Jetson via tether](Jetson_internet.md).

## Installing Nvidia SDK

After having configured the Internet access, we can proceed with the installation of Nvidia graphics card drivers.

1. Open Nvidia SDK Manager.
2. Proceed with the same selection as in [Flashing jetson with the Operating System](#flashing-jetson-with-the-operating-system) until module selection.
3. In the module selection, select the following:
<p align="center">
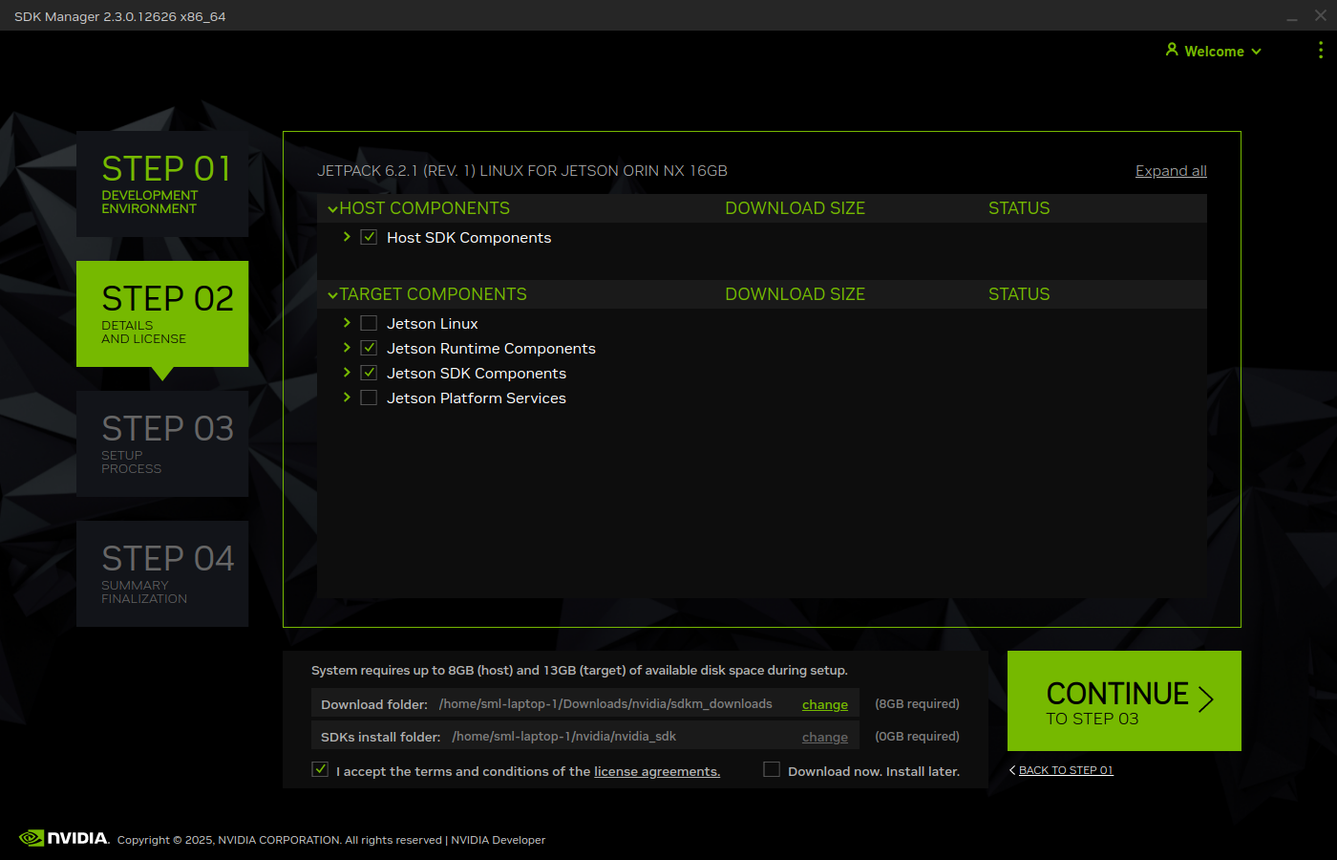
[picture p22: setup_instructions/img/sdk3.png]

</p>
4. After the download is complete, continue to flashing the device.
5. Select flashing over ssh and fill-in the IP address, username, and password. <strong>TIP!</strong> If by chance there are <code>apt</code> errors, ensure that the system date is set correctly to the current date.
6. We can verify whether CUDA has been sucessfully installed by running:\
   <code>nvcc --version</code>

## Software Setup After Installation

To install the development software, clone this repository onto Jetson or paste the contents of <code>BlueROV_Jetson_setup.sh</code> into a new file. Cloning the repository requires a SSH key assosiacted with your account added to the group's codebase (you will not be able to clone it otherwise).

<code>sudo chmod +x BlueROV_Jetson_setup.sh</code>\
<code>./BlueROV_Jetson_setup.sh</code>

It is imperative that the script executes for the current user and NOT with sudo. Using sudo will cause certain packages to not be installed and thus accessible for the default use

### Setting up remote desktop using NoVNC

To install novnc server, run novnc_setup.sh which atthis point should have already be invoked in the main installation script. To start the server manually, enter these commands into the terminal:\
<code>x11vnc -display :0 -rfbport 5900 -forever -shared -nopw</code> \
<code>websockify --web=/usr/share/novnc/ 0.0.0.0:6080 localhost:5900</code>

To access the remote desktop on your development machine, open your browser and input the Jetson's IP address followed by port 6080. For example:
<code>http://192.168.0.22:6080/</code>
For Jetson with IP 192.168.0.22 with vnc port 6080

### Setting up Nvidia TensorRT for YOLO acceleration

1. Log-in into your Nvidia developer account here: [https://docs.nvidia.com/deeplearning/tensorrt/latest/installing-tensorrt/installing.html](https://docs.nvidia.com/deeplearning/tensorrt/latest/installing-tensorrt/installing.html) and download <code> TensorRT 10.3 GA for L4T and CUDA 12.6 DEB local repo Package</code> under <code>TensorRT 10.3 GA for JetPack</code> for Ubuntu 22.04.
2. Using the terminal, install this example package: \
   <code>cd Downloads</code>
   <code>sudo dpkf -i nv-tensorrt-local-tegra-repo-ubuntu2204-10.3.0-cuda-12.6_1.0-1_arm64.deb</code>
3. After the installation, do what the prompt says and copy the keychain, for example: \
   <code>sudo cp /car/nv-tensorrt-local-tegra-repo-ubuntu2204-10.3.0-cuda-12.5/nv-tensorrt-local-tegra-E39D0E0C-keyring.gpg /usr/share/keyrings/</code>

## Reference Links

- [https://connecttech.com/resource-center/l4t-board-support-packages/](https://connecttech.com/resource-center/l4t-board-support-packages/)
- [https://connecttech.com/ftp/pdf/CTIM-00095_Boson_Boson22_Manual.pdf](https://connecttech.com/ftp/pdf/CTIM-00095_Boson_Boson22_Manual.pdf)
- [https://developer.nvidia.com/sdk-manager](https://developer.nvidia.com/sdk-manager)
- [https://support.connecttech.com/hc/en-us/articles/4416099515931-CTI-L4T-Board-Support-Package-Installation-for-NVIDIA-JetPack-with-Connect-Tech-Jetson-Carriers](https://support.connecttech.com/hc/en-us/articles/4416099515931-CTI-L4T-Board-Support-Package-Installation-for-NVIDIA-JetPack-with-Connect-Tech-Jetson-Carriers)
- [https://support.connecttech.com/hc/en-us/articles/4416086952603-Installing-Jetpack-SDK-Components-alongside-the-CTI-L4T-BSP](https://support.connecttech.com/hc/en-us/articles/4416086952603-Installing-Jetpack-SDK-Components-alongside-the-CTI-L4T-BSP)
- [https://ninjalabo.ai/blogs/jetson_pytorch.html](https://ninjalabo.ai/blogs/jetson_pytorch.html)
- [https://forums.developer.nvidia.com/t/building-opencv-with-cuda/285744](https://forums.developer.nvidia.com/t/building-opencv-with-cuda/285744)
- [https://github.com/AastaNV/JEP](https://github.com/AastaNV/JEP)
- [https://github.com/realsenseai/librealsense/blob/master/doc/installation_jetson.md](https://github.com/realsenseai/librealsense/blob/master/doc/installation_jetson.md)

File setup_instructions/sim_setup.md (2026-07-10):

## Installation process (in Linux):
>[!NOTE]
>We recommend using Ubuntu 22.04, ROS2 Humble and Gazebo Harmonic.

1. **Install DHSG PX4 fork and the DHSG custom gz models:**
    ```bash
    # 1) Clone DHSG PX4 fork
    git clone git@github.com:KTH-DHSG/PX4-Autopilot.git
    cd PX4-Autopilot
    
    # 2) Switch to DHSG branch with custom Gazebo models
    git checkout kth-model-changes
    
    # 3) Fetch all submodules at pinned versions
    git submodule sync --recursive
    git submodule update --init --recursive
    
    # 4) Install dependencies
    bash ./Tools/setup/ubuntu.sh
    
    # 5) Reboot recommended
    ```
    
2. **Build PX4 messages for ROS 2:**

   To communicate with the Pixhawk via ROS 2, you need its PX4 messages (available here: [PX4-msgs at GitHub](https://github.com/PX4/px4_msgs)) on your local machine:
    ```bash
    mkdir -p ~/px4_ws/src/
    cd ~/px4_ws/src/
    git clone git@github.com:PX4/px4_msgs.git
    cd ~/px4_ws
    colcon build
    source install/setup.bash
    ```
    
3. **Install QGroundControl:**
   
   QGroundControl is the ground control station used to interface with PX4 from a local machine. It is openly available here: [QGroundControl at GitHub](https://github.com/mavlink/qgroundcontrol).
    
    > ##### QGround Control Version
    >
    > We recommend using the latest daily build version available here: [QGroundControl Daily Builds](https://docs.qgroundcontrol.com/master/en/qgc-user-guide/releases/daily_builds.html#daily-builds).
    
    #### Setting up QGroundControl
    
    To build QGroundControl for Linux Ubuntu, you first need:
    ```bash
    sudo usermod -a -G dialout $USER
    sudo apt-get remove modemmanager -y
    sudo apt install gstreamer1.0-plugins-bad gstreamer1.0-libav gstreamer1.0-gl -y
    sudo apt install libfuse2 -y
    sudo apt install libxcb-xinerama0 libxkbcommon-x11-0 libxcb-cursor-dev -y
    ```
    
    Logout and login again to enable the change to user permissions.
    
    After downloading QGroundControl, make it executable:
    ```bash
    chmod +x ./QGroundControl-x86_64.AppImage
    ```
    
    To launch it, simply run:
    ```bash
    ./QGroundControl-x86_64.AppImage
    ```
    
4. **Running the simulator:**
   
    The BlueROV2 with PX4 controller can be simulated using Gazebo. Gazebo should have been installed when setting up required packages for `PX4-Autopilot`. If not, installation instructions for Gazebo can be found [here](https://gazebosim.org/docs/harmonic/install_ubuntu/).
    
    With Gazebo installed, navigate to your local PX4 Autopilot directory and run the simulation:
    
    ```bash
    make px4_sitl_uuv gz_uuv_bluerov2_heavy
    ```
    
    Optionally, to run with ROS 2 namespace:
    
    ```bash
    PX4_UXRCE_DDS_NS=<namespace> make px4_sitl_uuv gz_uuv_bluerov2_heavy
    ```

    You can also run the simulator with the KTH Water Tank by using:

    ```bash
    PX4_GZ_WORLD=kth_marinarium make px4_sitl_uuv gz_uuv_bluerov2_heavy
    ```

    There is also a version with the docking station:

    ```bash
    PX4_GZ_WORLD=kth_marinarium_docking make px4_sitl_uuv gz_uuv_bluerov2_heavy
    ```
    
    #### Running Micro-XRCE-DDS-Agent Locally
    
    PX4 uses Micro-XRCE-DDS as middleware to allow its uORB messages to be published and subscribed to on a companion computer as though they were ROS 2 topics. Although the Micro-XRCE-DDS-Agent is preconfigured on the Jetson, we recommend installing it locally as well for simulation, testing, and development.
    
    Install Micro-XRCE-DDS-Agent from snap-store:
    
    ```bash
    sudo snap install micro-xrce-dds-agent --edge
    ```
    
    Once installed, connect to the PX4 by running:
    
    - **For Ethernet and Simulator connections:**
        ```bash
        micro-xrce-dds-agent udp4 -p 8888
        ```
    - **For Serial connections:**
        ```bash
        micro-xrce-dds-agent serial --dev <serial-port>
        ```
    
    #### Subscribe to topics
    
    Similarly to the hardware version, you should now see the SITL topics being published in ROS 2:
    ```bash
    ros2 topic list
    ros2 topic echo /fmu/out/vehicle_attitude
    ```
    Make sure you have sourced the PX4-msgs (step 2) in the same terminal you are doing the publishing and subscribing.
    
    The hardware is now being mimicked in software!

6. **Teleoperating the BlueROV2:**

   You can now plug in a joystick to control the simulator with QGC. If you don't have one the easiest way is to enable the virtual joystick in QGroundControl as explained [here](https://docs.qgroundcontrol.com/Stable_V4.3/en/qgc-user-guide/settings_view/virtual_joystick.html). I recommend to play with it to get to know it, and to use only Position mode, Stabilized mode and Acro mode (Manual mode should only be used if necessary, but otherwise avoid it).

7. **Getting to Offboard mode:**

   To send input commands through ROS2, you need to setup the vehicle in Offboard mode in QGroundControl. Typically, it does not show in the mode section since it is hidden by default so you need to click on the right arrow at the top of the Mode selection, then turn on the *Edit Displayed Flight Modes" slides and turn off the *Offboard* slider.

8. **Sending ROS2 control actuation:**

   Next, you need to have a heartbeat ROS2 node that constantly sends the offboard signal non-stop at more than 10Hz, this will allow you to arm the vehicle in QGC since by default Offboard will not let you. Note that you arm by clicking on the *Ready To Fly* text, then *Arm* and then moving the slider to the right.
    
    Now you can send inputs through the ``/fmu/in/vehicle_thrust_setpoint`` and ``/fmu/in/vehicle_torque_setpoint`` topics, the ``/fmu/in/vehicle_rates_setpoint`` topic or the ``/fmu/in/actuator_motors`` topic (depending on your heartbeat node type). You can find an example of my thrust_and_torque hearbeat node here: [https://kth-my.sharepoint.com/:u:/g/personal/vnfa_ug_kth_se/IQB1s1Xqxo_QSptLPT2AlvvkAd5DF3hMsSnaLL8aPBzlZ88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.](https://kth-my.sharepoint.com/:u:/g/personal/vnfa_ug_kth_se/IQB1s1Xqxo_QSptLPT2AlvvkAZ1-ba43ZigrbaFGL0r4nk8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). I recommend to always use thrust_and_torque.

9. If you want an example of a ROS2 controller working in the simulator you can check the **Stabilized Control** or **PID Position Control** from [here](https://github.com/KTH-DHSG/bluerov2_control). You may need to ask for permission to see the repo, if so email [Victor](vnfa@kth.se).

10. **Running multiple BlueROV2s:**

    After cloning and building the [`bluerov2_control`](https://github.com/KTH-DHSG/bluerov2_control) ROS 2 package, launch three BlueROV2 Heavy vehicles in the Marinarium docking world with:

    ```bash
    cd ~/px4_ws
    source install/setup.bash
    ros2 launch bluerov2_control multi_bluerov2_sim.launch.py
    ```

    The vehicles use the ROS 2 namespaces:

    ```text
    /itrl_rov_1
    /itrl_rov_2
    /itrl_rov_3
    ```

    The number of vehicles, namespaces, spawn delays and instance IDs can be edited in:

    ```text
    bluerov2_control/launch/multi_bluerov2_sim.launch.py
    ```

    The initial positions can be edited through the `rov_1_pose`, `rov_2_pose` and `rov_3_pose` launch arguments. For example:

    ```bash
    ros2 launch bluerov2_control multi_bluerov2_sim.launch.py \
        rov_1_pose:="-1.15,-2.20,-95.70,0,0,0" \
        rov_2_pose:="0.10,-2.20,-95.70,0,0,0" \
        rov_3_pose:="-2.40,-2.20,-95.70,0,0,0"
    ```

    If the `PX4-Autopilot` path cannot be found automatically you can pass its path directly with:

    ```bash
    ros2 launch bluerov2_control multi_bluerov2_sim.launch.py \
        px4_dir:=/absolute/path/to/PX4-Autopilot
    ```

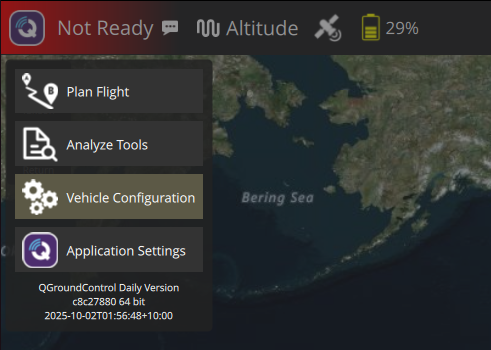
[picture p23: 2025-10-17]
setup_instructions/img/vehicle_conf_go_to.png

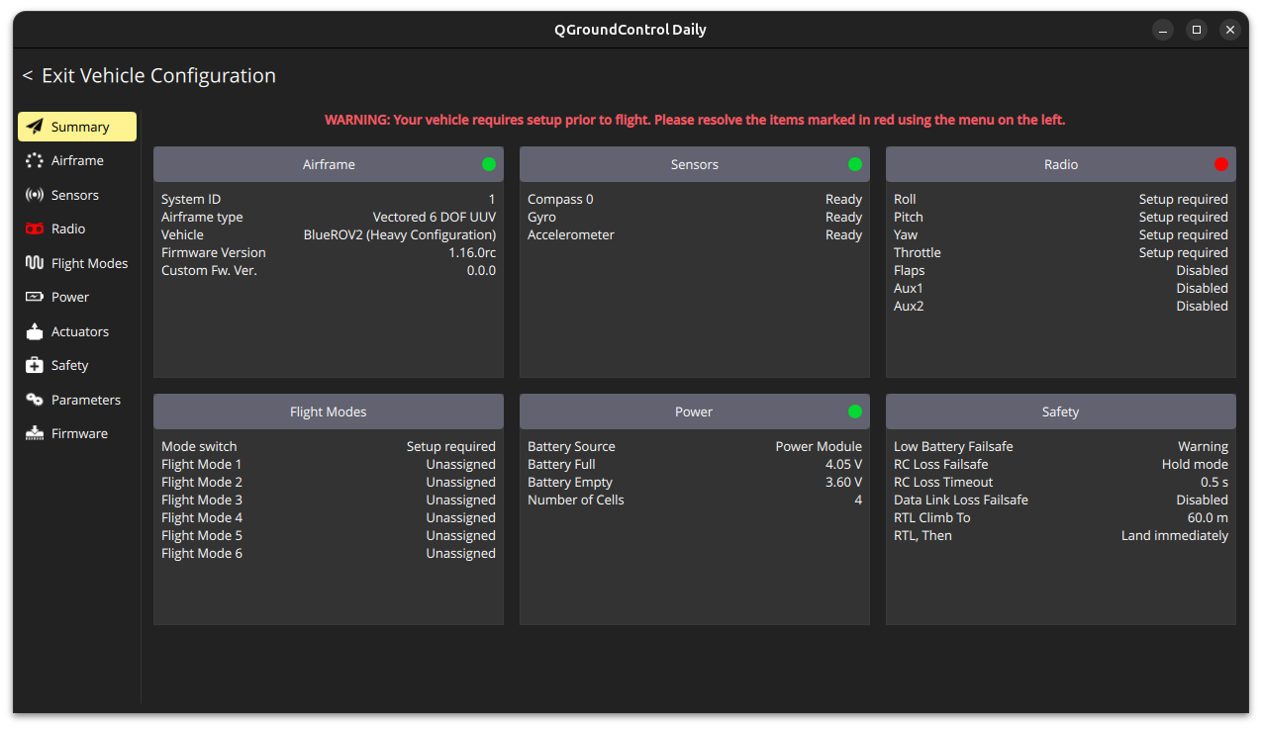
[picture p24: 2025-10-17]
setup_instructions/img/vehicle_conf.png

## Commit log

2025-10-03 jetson setup
2025-10-28 added STLs
    [CameraHold.stl, JetsonHold_ToUseAtBackside.stl, JetsonHold_ToUseAtFrontside.stl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]
2025-10-28 Fix PWM references and update actuator image
    Corrected 'PWN' to 'PWM' and updated image source.
2025-10-28 Update hardware setup instructions for clarity
    Clarified descriptions of battery enclosure and connection types in hardware setup.
2025-11-14 added jetson OS and updated .sh
2025-11-17 brov wiring diagram and jetson internet connection setup
2025-11-27 added jetson setup readme
2025-11-27 added jetson CUDO readme
2026-02-20 Enhance passive gripper description in README
    Updated the passive gripper item to include testing with a large handle.
2026-02-25 Enhance battery connection instructions for BlueROV2
    Added additional verification method for ESC startup.
2026-02-26 Fix link reference for lights switch setup
2026-02-27 Update TODOs in README for stereo vision and assembly
2026-03-13 Updated Jetson setup with tensorrt instructions
2026-04-10 docking station files added
    [DockingStationv2.FCStd, DockingStationv2.obj, DockingStationv2.step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]
2026-04-10 added correct OBJ and MTL file
    [docking station simplified.obj]
2026-04-17 Jetson Internet setup fixes
2026-04-17 jetson internet setup script and minor typo fixes
2026-04-17 jetson internet fixed
2026-04-17 jetson internet fixed, removed stray files
2026-05-21 fixed README reference to Jetson setup file
